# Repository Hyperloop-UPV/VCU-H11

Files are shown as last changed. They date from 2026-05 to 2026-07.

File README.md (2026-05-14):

# VCU-H11

Vehicle Control Unit firmware for Hyperloop UPV.

The VCU is the pod-level controller for the H11 custom board based on the STM32H723ZGT6. It coordinates the vehicle-facing control and telemetry functions around cooling, pressure regulation, braking support signals, SDC state, flow and temperature sensing, CAN, Ethernet, SD storage, and board status indication.

## Responsibilities

The firmware is responsible for:

- Initializing the VCU hardware through ST-LIB.
- Managing VCU operational modes.
- Reading pressure, temperature, flow, SDC, brake, and SD-card related inputs.
- Driving status LEDs and VCU actuators such as the two cooling pump outputs, electrovalve, PWM pressure regulator command path, brake reset, and CAN silent control.
- Publishing VCU telemetry and receiving commands through the generated packet interface.
- Evaluating protections and reporting diagnostics through ST-LIB infrastructure.

## Architecture

VCU-H11 is a C++23 STM32 firmware project built around ST-LIB.

Application code is organized around these entry points:

- `Core/Src/main.cpp`: firmware entry point.
- `Core/Inc/VCU.hpp`: VCU facade and `ST_LIB::Board<...>` definition.
- `Core/Inc/VCU_TYPES.hpp`: Board device declarations, runtime instances, sensors, and VCU state.
- `Core/Inc/Pinout/Pinout.hpp`: board pin aliases with firmware-facing names.
- `Core/Inc/StateMachine/VCU_StateMachine.hpp`: operational state machine.
- `Core/Inc/Code_generation/JSON_ADE/boards/VCU/`: packet schema inputs for generated communication code.

All hardware access should go through ST-LIB. Application code should use the highest-level ST-LIB abstraction that fits the hardware role, for example `LinearSensor` for linear analog sensors, `NTC` for NTC channels, `SensorInterrupt`/`EXTIDomain` for edge-triggered sensors, and Board-managed domain instances for lower-level peripherals.

Fault state ownership belongs to ST-LIB infrastructure. The VCU application state machine should describe operational modes, while protections and diagnostics handle fault behavior.

## Hardware References

Hardware design references are stored under `docs/`:

- `VCU.ioc`: STM32CubeMX pin and peripheral role reference.
- `VCU_H11G.zip`: Altium project archive.
- `Schematic PDF_[No Variations].pdf`: schematic PDF export.
- `Gerber for PCB.PcbDoc.zip`: PCB fabrication output.
- `STEP_[No Variations] for PCB.PcbDoc.step`: mechanical model.
- `Assembly Drawings_[No Variations].pdf`: assembly drawing export.
- `BOM_[No Variations].csv`: bill of materials export.

## Build And Flash

Use the local `hyper` helper CLI for common workflows:

```sh
./hyper doctor
./hyper build main --preset board-debug --board-name VCU
./hyper build main --preset board-debug-eth-lan8700 --board-name VCU
./hyper run main --preset board-debug --board-name VCU --uart
```

Useful environment variables:

- `HYPER_DEFAULT_PRESET`
- `HYPER_FLASH_METHOD`
- `HYPER_UART_PORT`
- `HYPER_UART_BAUD`
- `HYPER_UART_TOOL`

For UART sessions, `tio` is the recommended terminal tool.

## Packet Generation

The packet interface is generated from the ADJ schema for `BOARD_NAME=VCU`:

```text
Core/Inc/Code_generation/JSON_ADE/boards/VCU/
```

CMake regenerates packet headers during configure. Manual regeneration is also available:

```sh
python3 Core/Inc/Code_generation/Generator.py VCU
```

Generated packet headers are build outputs and should not be edited by hand:

- `Core/Inc/Communications/Packets/DataPackets.hpp`
- `Core/Inc/Communications/Packets/OrderPackets.hpp`

## Documentation

Project-specific AI and maintenance context:

- `AGENTS.md`
- `docs/ai/vcu-context.md`

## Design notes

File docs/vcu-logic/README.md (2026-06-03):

# VCU Logic Documentation

This folder documents the Vehicle Control Unit business logic extracted from the previous board codebase at `/Users/jsaegar/hyper-src/VCU-H10-V2`.

The H10-V2 project used an old ST-LIB API and several implementation details are no longer valid for H11. The durable part is the control intent: what the VCU supervises, which commands it accepts, how it gates them by state, what telemetry it reports, and what conditions push the vehicle into a safe fault response.

Use these documents as the behavioral reference when implementing H11 firmware. Do not copy the old H10 hardware-access style.

## Document Map

- [Purpose and Responsibilities](01-purpose-and-responsibilities.md): what the VCU is responsible for in the vehicle.
- [State Machine](02-state-machine.md): the general and operational states, transitions, and cyclic work.
- [Communications and Orders](03-communications-and-orders.md): sockets, packet flow, order handling, and remote-board acknowledgements.
- [Local Subsystems](04-local-subsystems.md): brakes, pressure regulation, pumps, sensors, and LEDs.
- [Protections and Faults](05-protections-and-faults.md): fault triggers, safety actions, and unresolved safety questions.
- [H11 Porting Notes](06-h11-porting-notes.md): how to carry the H10 behavior into the current H11 architecture.

## Mental Model

The VCU is the vehicle master. It is the coordinator between the operator/control station, local hardware attached to the VCU, and remote vehicle boards such as HVBMS, PCU, and LCU.

At a high level, each loop does four jobs:

1. Maintain infrastructure and communications.
2. Advance the vehicle state machines.
3. Read local sensors and publish telemetry.
4. Process accepted orders, forward remote requests, and fault if safety assumptions are violated.

The VCU does not directly implement every vehicle subsystem. Instead, it arbitrates when other boards may act. For example, it does not close the high-voltage contactors itself; it sends the contactor order to HVBMS, waits until HVBMS reports the expected state, then updates the VCU's own operational state.

## Source Caveats

The inspected H10-V2 snapshot contains legacy and partially disabled code paths:

- `state_machine.json` is a template example. The real VCU state machine is in `Core/Inc/state_machine.hpp`.
- BMSL, LCU, BCU, and some propulsion/charging paths are referenced, but some sockets or orders are commented out in the inspected snapshot.
- Some names are Spanish or legacy abbreviations. H11 firmware should keep English concept names.
- The H10 code modeled `Fault` as a general state. H11 should preserve the fault behavior through ST-LIB protections, diagnostics, and fault policy infrastructure rather than adding `Fault` to the application operational state.

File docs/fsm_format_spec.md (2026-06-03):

# Formato declarativo para definir máquinas de estados finitas

## 1. Objetivo

Este documento define un formato declarativo, legible por humanos y procesable por herramientas, para describir máquinas de estados finitas, o FSMs, de forma suficientemente precisa como para:

- Generar código automáticamente.
- Generar diagramas de estados.
- Generar tests unitarios.
- Revisar el comportamiento del sistema sin leer código imperativo.
- Pasar la especificación a una IA o agente de generación de código sin depender de texto ambiguo.

El formato recomendado es YAML, aunque puede traducirse directamente a JSON.

La idea principal es separar:

- La estructura de la máquina.
- La lógica de transición.
- Las condiciones de transición.
- Las acciones ejecutadas.
- La implementación concreta del hardware o del sistema real.

Una máquina de estados bien definida no debería depender de frases como “cuando pase algo, cambia a tal modo”. Debería declarar explícitamente qué evento provoca qué transición, bajo qué condición y qué acciones se ejecutan.

---

## 2. Modelo formal

Una máquina de estados se puede definir como:

```text
FSM = (S, E, G, A, T, s0, C)
```

Donde:

| Símbolo | Significado |
|---|---|
| `S` | Conjunto de estados |
| `E` | Conjunto de eventos |
| `G` | Conjunto de guards o condiciones booleanas |
| `A` | Conjunto de acciones |
| `T` | Conjunto de transiciones |
| `s0` | Estado inicial |
| `C` | Contexto o datos internos usados por la FSM |

Una transición se puede expresar como:

```text
estado_origen + evento + guard -> estado_destino + acciones
```

Ejemplo:

```text
IDLE + START [battery_connected && no_fault] -> PRECHARGE / enable_precharge(), reset_timer()
```

En YAML:

```yaml
- from: IDLE
  event: START
  guard: battery_connected && no_fault
  to: PRECHARGE
  actions:
    - enable_precharge
    - reset_timer
```

---

## 3. Estructura general del documento

Una especificación completa puede tener esta forma:

```yaml
schema_version: "1.0"
machine: ChargerFSM
description: Máquina de estados para control de carga de batería.

initial_state: IDLE

context:
  variables: []

states: []

events: []

guards: []

actions: []

transitions: []
```

Los campos principales son:

| Campo | Obligatorio | Descripción |
|---|---:|---|
| `schema_version` | Sí | Versión del formato usado |
| `machine` | Sí | Nombre de la máquina de estados |
| `description` | No | Descripción general |
| `initial_state` | Sí | Estado inicial |
| `context` | No | Variables internas usadas por guards y acciones |
| `states` | Sí | Lista o mapa de estados |
| `events` | Sí | Lista de eventos que la máquina acepta |
| `guards` | No | Lista de condiciones booleanas |
| `actions` | No | Lista de acciones ejecutables |
| `transitions` | Sí | Lista de transiciones |

---

## 4. `schema_version`

Indica la versión del formato de especificación.

```yaml
schema_version: "1.0"
```

Esto permite evolucionar el formato en el futuro sin romper generadores de código antiguos.

---

## 5. `machine`

Nombre lógico de la máquina de estados.

```yaml
machine: ChargerFSM
```

Recomendaciones:

- Usar `PascalCase`.
- Evitar espacios.
- Usar un nombre que pueda convertirse fácilmente en prefijo de funciones o tipos.

Por ejemplo, para C:

```c
typedef enum ChargerFSM_State { ... } ChargerFSM_State;
void ChargerFSM_dispatch(...);
```

---

## 6. `description`

Descripción humana del propósito de la máquina.

```yaml
description: >
  Controla el proceso de carga de una batería de alto voltaje,
  incluyendo precarga, carga activa, finalización y fallos.
```

Este campo no debería contener lógica normativa. La lógica debe estar en `transitions`, `guards` y `actions`.

---

## 7. `initial_state`

Estado inicial de la máquina.

```yaml
initial_state: IDLE
```

Debe coincidir exactamente con uno de los estados definidos en `states`.

---

## 8. `context`

El contexto define los datos que la FSM puede consultar o modificar.

Ejemplo:

```yaml
context:
  variables:
    - name: battery_voltage
      type: float
      unit: V
      access: read
      description: Tensión medida en la batería.

    - name: charge_current
      type: float
      unit: A
      access: read
      description: Corriente de carga medida.

    - name: fault_flags
      type: uint32_t
      access: read_write
      description: Máscara de bits con fallos activos.
```

Campos recomendados por variable:

| Campo | Obligatorio | Descripción |
|---|---:|---|
| `name` | Sí | Nombre de la variable |
| `type` | Sí | Tipo lógico o tipo de lenguaje destino |
| `unit` | No | Unidad física, si aplica |
| `access` | No | `read`, `write` o `read_write` |
| `description` | No | Descripción humana |
| `initial_value` | No | Valor inicial |
| `range` | No | Rango válido |

Ejemplo con rango:

```yaml
- name: battery_voltage
  type: float
  unit: V
  range:
    min: 0.0
    max: 500.0
```

---

## 9. `states`

Los estados representan situaciones discretas de la FSM.

Formato simple:

```yaml
states:
  - IDLE
  - PRECHARGE
  - CHARGING
  - DONE
  - FAULT
```

Formato recomendado:

```yaml
states:
  - name: IDLE
    description: Sistema parado esperando orden de arranque.
    on_entry:
      - disable_pwm
    on_exit: []

  - name: CHARGING
    description: Carga activa de la batería.
    on_entry:
      - enable_pwm
    on_exit:
      - disable_pwm
```

Campos posibles:

| Campo | Obligatorio | Descripción |
|---|---:|---|
| `name` | Sí | Nombre del estado |
| `description` | No | Descripción humana |
| `type` | No | Tipo especial: `normal`, `final`, `fault`, etc. |
| `on_entry` | No | Acciones al entrar al estado |
| `on_exit` | No | Acciones al salir del estado |
| `do` | No | Acciones periódicas mientras se permanece en el estado |
| `timeout` | No | Timeout asociado al estado |
| `internal_transitions` | No | Transiciones internas que no cambian de estado |
| `metadata` | No | Información extra para herramientas |

---

## 10. Acciones `on_entry`, `on_exit` y `do`

### `on_entry`

Acciones ejecutadas al entrar en un estado.

```yaml
on_entry:
  - enable_pwm
  - reset_state_timer
```

### `on_exit`

Acciones ejecutadas al salir de un estado.

```yaml
on_exit:
  - disable_pwm
```

### `do`

Acciones ejecutadas periódicamente mientras la FSM permanece en el estado.

```yaml
do:
  - update_control_loop
  - monitor_temperature
```

Recomendación: `do` debería usarse con cuidado. En sistemas embebidos suele corresponder a una función llamada periódicamente desde un tick o scheduler.

---

## 11. `timeout` de estado

Un estado puede tener un timeout.

```yaml
timeout:
  duration_ms: 5000
  event: TIMEOUT
  description: Si la precarga tarda más de 5 s, se genera TIMEOUT.
```

Campos posibles:

| Campo | Obligatorio | Descripción |
|---|---:|---|
| `duration_ms` | Sí | Duración en milisegundos |
| `event` | Sí | Evento generado al cumplirse el timeout |
| `description` | No | Descripción humana |

El generador puede implementar esto como:

- Temporizador interno de estado.
- Evento sintético generado por el scheduler.
- Comparación de timestamps.

---

## 12. `events`

Los eventos son entradas discretas que la FSM procesa.

Formato simple:

```yaml
events:
  - START
  - STOP
  - ADC_UPDATE
  - TIMEOUT
  - RESET
```

Formato recomendado:

```yaml
events:
  - name: START
    source: user_command
    description: Solicitud externa para iniciar la carga.

  - name: ADC_UPDATE
    source: periodic_task
    payload:
      - name: battery_voltage
        type: float
      - name: charge_current
        type: float
    description: Nueva muestra de ADC disponible.
```

Campos posibles:

| Campo | Obligatorio | Descripción |
|---|---:|---|
| `name` | Sí | Nombre del evento |
| `source` | No | Origen lógico del evento |
| `description` | No | Descripción humana |
| `payload` | No | Datos asociados al evento |
| `priority` | No | Prioridad del evento |

---

## 13. `guards`

Los guards son condiciones booleanas que habilitan o bloquean transiciones.

```yaml
guards:
  - name: battery_connected
    expression: battery_voltage > 50.0
    description: La batería está conectada si su tensión supera 50 V.
```

Campos posibles:

| Campo | Obligatorio | Descripción |
|---|---:|---|
| `name` | Sí | Nombre del guard |
| `expression` | No | Expresión lógica abstracta |
| `function` | No | Nombre de función que lo implementa |
| `description` | No | Descripción humana |
| `dependencies` | No | Variables de contexto usadas |

Hay dos estilos válidos.

### 13.1 Guard como expresión

```yaml
- name: current_too_high
  expression: charge_current > max_charge_current
```

El generador puede convertir esto a código si el lenguaje y las variables están bien definidas.

### 13.2 Guard como función externa

```yaml
- name: current_too_high
  function: guard_current_too_high
```

El generador solo declara la función, pero no la implementa.

Ejemplo en C:

```c
bool guard_current_too_high(const ChargerFSM_Context *ctx);
```

---

## 14. `actions`

Las acciones son operaciones ejecutadas por la FSM.

```yaml
actions:
  - name: enable_pwm
    function: action_enable_pwm
    description: Habilita la etapa de potencia.
```

Campos posibles:

| Campo | Obligatorio | Descripción |
|---|---:|---|
| `name` | Sí | Nombre lógico de la acción |
| `function` | No | Nombre de función destino |
| `description` | No | Descripción humana |
| `parameters` | No | Parámetros |
| `modifies` | No | Variables de contexto modificadas |
| `blocking` | No | Indica si la acción bloquea |

Ejemplo con parámetros:

```yaml
- name: set_fault_reason
  function: action_set_fault_reason
  parameters:
    - name: reason
      type: FaultReason
```

Uso en una transición:

```yaml
actions:
  - name: set_fault_reason
    args:
      reason: OVERCURRENT
```

---

## 15. `transitions`

Las transiciones definen el comportamiento principal.

```yaml
transitions:
  - from: IDLE
    event: START
    guard: battery_connected && no_fault
    to: PRECHARGE
    actions:
      - reset_timer
      - enable_precharge
```

Campos posibles:

| Campo | Obligatorio | Descripción |
|---|---:|---|
| `from` | Sí | Estado origen |
| `event` | Sí | Evento que dispara la transición |
| `guard` | No | Condición necesaria |
| `to` | Sí | Estado destino |
| `actions` | No | Acciones asociadas a la transición |
| `priority` | No | Prioridad explícita |
| `description` | No | Descripción humana |

---

## 16. Orden y prioridad de transiciones

Si varias transiciones tienen el mismo `from` y el mismo `event`, puede haber ambigüedad.

Ejemplo:

```yaml
- from: CHARGING
  event: ADC_UPDATE
  guard: current_too_high
  to: FAULT

- from: CHARGING
  event: ADC_UPDATE
  guard: voltage_reached
  to: DONE
```

Si ambas condiciones pueden ser verdaderas a la vez, el resultado depende del orden o de una prioridad explícita.

Forma recomendada:

```yaml
- from: CHARGING
  event: ADC_UPDATE
  guard: current_too_high
  to: FAULT
  priority: 10

- from: CHARGING
  event: ADC_UPDATE
  guard: voltage_reached
  to: DONE
  priority: 20
```

Regla recomendada:

- Menor valor de `priority` implica mayor prioridad.
- Si no hay `priority`, se respeta el orden de aparición.
- Un validador debería avisar si hay condiciones potencialmente solapadas.

---

## 17. Transiciones globales

Una transición global aplica desde cualquier estado.

```yaml
- from: "*"
  event: EMERGENCY_STOP
  to: FAULT
  actions:
    - disable_pwm
    - open_contactor
    - set_fault_emergency_stop
  priority: 0
```

Uso típico:

- Parada de emergencia.
- Fallo crítico.
- Reset global.
- Pérdida de comunicación.

---

## 18. Transiciones internas

Una transición interna procesa un evento sin cambiar de estado.

```yaml
- from: CHARGING
  event: ADC_UPDATE
  guard: normal_operating_conditions
  to: CHARGING
  internal: true
  actions:
    - update_control_loop
```

También puede representarse dentro del estado:

```yaml
states:
  - name: CHARGING
    internal_transitions:
      - event: ADC_UPDATE
        guard: normal_operating_conditions
        actions:
          - update_control_loop
```

Recomendación:

- Usar `internal: true` si quieres que no se ejecuten `on_exit` ni `on_entry`.
- Usar `to: CHARGING` sin `internal: true` si quieres que sí se ejecuten salida y entrada del mismo estado.

---

## 19. Transiciones sin guard

Una transición sin guard se considera siempre habilitada.

```yaml
- from: IDLE
  event: START
  to: RUNNING
```

Equivale a:

```yaml
guard: true
```

---

## 20. Acciones parametrizadas en transiciones

Las acciones pueden llamarse directamente por nombre:

```yaml
actions:
  - disable_pwm
```

O con argumentos:

```yaml
actions:
  - name: set_fault_reason
    args:
      reason: OVERTEMPERATURE
  - name: log_event
    args:
      event_id: CHARGER_FAULT
```

Esto permite generar llamadas como:

```c
action_set_fault_reason(ctx, FAULT_OVERTEMPERATURE);
action_log_event(ctx, CHARGER_FAULT);
```

---

## 21. Estados finales

Un estado final representa una condición terminal.

```yaml
- name: DONE
  type: final
  description: Proceso completado correctamente.
```

Un generador puede usar esto para:

- No esperar más eventos.
- Generar una función `is_finished()`.
- Marcar el estado como terminal en un diagrama.

---

## 22. Estados de fallo

Un estado de fallo representa una condición anómala.

```yaml
- name: FAULT
  type: fault
  on_entry:
    - disable_pwm
    - open_contactor
    - log_fault
```

No todos los fallos tienen que ir al mismo estado, pero suele ser útil tener un estado `FAULT` común y guardar la causa del fallo en el contexto.

---

## 23. Historial de estado

Algunas máquinas jerárquicas necesitan recordar el último subestado activo.

Ejemplo:

```yaml
history:
  enabled: true
  type: shallow
```

Tipos posibles:

| Tipo | Significado |
|---|---|
| `shallow` | Recuerda solo el subestado directo |
| `deep` | Recuerda toda la jerarquía de subestados |

Este campo es opcional y solo tiene sentido en máquinas jerárquicas.

---

## 24. Estados jerárquicos

Para máquinas complejas se pueden usar estados con subestados.

```yaml
states:
  - name: ACTIVE
    initial_state: PRECHARGE
    substates:
      - name: PRECHARGE
      - name: CHARGING
      - name: BALANCING
```

Esto representa una máquina jerárquica tipo statechart.

Recomendación:

- Usar FSM plana para sistemas pequeños.
- Usar jerarquía cuando haya estados que compartan transiciones, acciones o comportamiento común.

---

## 25. Eventos diferidos

Un estado puede diferir eventos para procesarlos más tarde.

```yaml
states:
  - name: PRECHARGE
    defer:
      - START_BALANCING
```

Esto significa que, si llega `START_BALANCING` durante `PRECHARGE`, no se descarta, sino que se guarda hasta que la FSM entre en un estado donde pueda procesarlo.

---

## 26. Eventos ignorados explícitamente

Puedes declarar eventos ignorados para dejar claro que no es un olvido.

```yaml
states:
  - name: IDLE
    ignore:
      - ADC_UPDATE
      - TIMEOUT
```

Esto ayuda a diferenciar entre:

- Evento no contemplado por error.
- Evento ignorado intencionadamente.

---

## 27. Política para eventos no manejados

Puede definirse a nivel global.

```yaml
unhandled_event_policy:
  behavior: ignore
  action: log_unhandled_event
```

Opciones típicas:

| Valor | Significado |
|---|---|
| `ignore` | Ignorar el evento |
| `log` | Registrar el evento |
| `fault` | Ir a estado de fallo |
| `assert` | Disparar una aserción en debug |

---

## 28. Invariantes de estado

Un invariante es una condición que debe cumplirse mientras la FSM esté en un estado.

```yaml
states:
  - name: CHARGING
    invariants:
      - pwm_enabled == true
      - contactor_closed == true
```

Si un invariante falla, el sistema puede:

- Registrar error.
- Ir a `FAULT`.
- Activar una aserción en debug.

---

## 29. Validaciones recomendadas

Un validador de especificación debería comprobar:

1. `initial_state` existe en `states`.
2. Todos los `from` existen, salvo `"*"`.
3. Todos los `to` existen.
4. Todos los `event` existen.
5. Todos los guards usados existen o son expresiones válidas.
6. Todas las acciones usadas existen.
7. No hay estados inalcanzables, salvo que estén marcados como intencionados.
8. No hay transiciones ambiguas sin prioridad.
9. No hay estados sin salida salvo estados `final` o `fault`.
10. No hay eventos definidos pero nunca usados, salvo que estén marcados como reservados.

---

## 30. Generación de código

Un generador puede producir:

- Enumeraciones de estados.
- Enumeraciones de eventos.
- Estructura de contexto.
- Función `init`.
- Función `dispatch`.
- Función `tick` para timeouts y acciones `do`.
- Prototipos de guards.
- Prototipos de acciones.
- Tabla de transiciones.
- Tests unitarios.

Ejemplo de API generada en C:

```c
typedef enum {
    CHARGER_STATE_IDLE,
    CHARGER_STATE_PRECHARGE,
    CHARGER_STATE_CHARGING,
    CHARGER_STATE_DONE,
    CHARGER_STATE_FAULT
} ChargerFSM_State;

typedef enum {
    CHARGER_EVENT_START,
    CHARGER_EVENT_STOP,
    CHARGER_EVENT_ADC_UPDATE,
    CHARGER_EVENT_TIMEOUT,
    CHARGER_EVENT_RESET
} ChargerFSM_Event;

void ChargerFSM_init(ChargerFSM_Context *ctx);
void ChargerFSM_dispatch(ChargerFSM_Context *ctx, ChargerFSM_Event event);
void ChargerFSM_tick(ChargerFSM_Context *ctx, uint32_t elapsed_ms);
ChargerFSM_State ChargerFSM_get_state(const ChargerFSM_Context *ctx);
```

---

## 31. Reglas recomendadas para IA o agentes de código

Cuando se pase esta especificación a una IA, conviene añadir instrucciones como:

```text
Generate production-quality C code from this FSM specification.

Rules:
- Do not invent states, events, guards or actions.
- Preserve transition priority.
- Use the order listed when priority is not specified.
- Generate external prototypes for guards and actions.
- Do not implement hardware-specific functions unless explicitly defined.
- Generate unit-testable code.
- If the FSM specification is ambiguous, mark the affected part as TODO instead of inventing behavior.
```

---

## 32. Plantilla mínima

```yaml
schema_version: "1.0"
machine: ExampleFSM
initial_state: IDLE

states:
  - name: IDLE
  - name: RUNNING
  - name: FAULT
    type: fault

events:
  - name: START
  - name: STOP
  - name: ERROR
  - name: RESET

guards:
  - name: no_fault
    expression: fault_flags == 0

actions:
  - name: start_system
  - name: stop_system
  - name: clear_faults

transitions:
  - from: IDLE
    event: START
    guard: no_fault
    to: RUNNING
    actions:
      - start_system

  - from: RUNNING
    event: STOP
    to: IDLE
    actions:
      - stop_system

  - from: "*"
    event: ERROR
    to: FAULT
    actions:
      - stop_system

  - from: FAULT
    event: RESET
    to: IDLE
    actions:
      - clear_faults
```

---

## 33. Plantilla completa recomendada

```yaml
schema_version: "1.0"
machine: NameFSM
description: Descripción general de la máquina.

initial_state: IDLE

unhandled_event_policy:
  behavior: log
  action: log_unhandled_event

context:
  variables:
    - name: variable_name
      type: uint32_t
      access: read_write
      description: Descripción.

states:
  - name: IDLE
    type: normal
    description: Estado inicial.
    on_entry: []
    on_exit: []
    do: []
    ignore: []
    defer: []
    invariants: []

  - name: FAULT
    type: fault
    on_entry:
      - safe_shutdown

events:
  - name: START
    source: external
    description: Evento de arranque.

guards:
  - name: can_start
    expression: fault_flags == 0
    dependencies:
      - fault_flags

actions:
  - name: safe_shutdown
    function: action_safe_shutdown
    description: Lleva el sistema a estado seguro.

transitions:
  - from: IDLE
    event: START
    guard: can_start
    to: RUNNING
    actions:
      - initialize_system
    priority: 10
    description: Arranca el sistema si no hay fallos.
```

---

## 34. Recomendaciones de estilo

- Nombres de estados en `UPPER_SNAKE_CASE`.
- Nombres de eventos en `UPPER_SNAKE_CASE`.
- Nombres de guards en `lower_snake_case`.
- Nombres de acciones en `lower_snake_case`.
- Evitar lógica compleja dentro de `transitions`.
- Dar prioridad explícita a transiciones críticas de seguridad.
- Separar la FSM del hardware.
- No esconder comportamiento en descripciones en lenguaje natural.

---

## 35. Regla práctica

Una buena especificación de FSM debería poder responder claramente a estas preguntas:

1. ¿En qué estado empieza?
2. ¿Qué eventos acepta?
3. ¿Qué puede pasar desde cada estado?
4. ¿Qué condiciones bloquean o permiten cada transición?
5. ¿Qué acciones se ejecutan al entrar, salir o cambiar de estado?
6. ¿Qué pasa ante eventos no esperados?
7. ¿Qué pasa ante errores o timeouts?
8. ¿Hay transiciones críticas con prioridad clara?

Si alguna de estas preguntas no se puede responder leyendo el YAML, la máquina todavía no está suficientemente formalizada.

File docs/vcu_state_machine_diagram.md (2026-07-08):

# VCU State Machine Diagram

This diagram follows `docs/vcu_state_machine.yaml`.

```mermaid
stateDiagram-v2
    direction LR

    [*] --> IDLE

    IDLE: IDLE\nbrake, open contactors\nwait for required links
    CONNECTED: CONNECTED\nbrake, open contactors\nwait for MANTEINANCE or PRECHARGE
    MANTEINANCE: MANTEINANCE\nunbrake\nwait for STOP
    PRECHARGING: PRECHARGING\nsend precharge\nwait for STOP or HVBMS completion
    HV_ACTIVE: HV_ACTIVE\nwait for STOP or UNBRAKE
    READY: READY\nunbrake\nwait for BRAKE/STOP/PROPULSION/LEVITATION
    PROPULSION: PROPULSION\nforward propulsion orders
    STATIC_LEVITATION: STATIC_LEVITATION\nforward static levitation orders
    DYNAMIC_LEVITATION: DYNAMIC_LEVITATION\nforward dynamic levitation orders
    FAULT: FAULT\nopen SDC, fault LED,\npropagate fault, open contactors

    IDLE --> CONNECTED: CONNECTIONS_READY\ncontrol station + required boards connected

    CONNECTED --> MANTEINANCE: ORDER_MANTEINANCE
    CONNECTED --> PRECHARGING: ORDER_PRECHARGE

    MANTEINANCE --> CONNECTED: ORDER_STOP

    PRECHARGING --> CONNECTED: ORDER_STOP
    PRECHARGING --> HV_ACTIVE: PRECHARGE_COMPLETE\nfrom HVBMS

    HV_ACTIVE --> CONNECTED: ORDER_STOP
    HV_ACTIVE --> READY: ORDER_UNBRAKE

    READY --> CONNECTED: ORDER_STOP
    READY --> HV_ACTIVE: ORDER_BRAKE
    READY --> PROPULSION: ORDER_PROPULSION
    READY --> STATIC_LEVITATION: ORDER_STATIC_LEVITATION
    READY --> DYNAMIC_LEVITATION: ORDER_DYNAMIC_LEVITATION

    STATIC_LEVITATION --> DYNAMIC_LEVITATION: ORDER_DYNAMIC_LEVITATION

    PROPULSION --> HV_ACTIVE: ORDER_BRAKE\nbrake, keep contactors closed
    STATIC_LEVITATION --> HV_ACTIVE: ORDER_BRAKE\nbrake, keep contactors closed
    DYNAMIC_LEVITATION --> HV_ACTIVE: ORDER_BRAKE\nbrake, keep contactors closed

    PROPULSION --> CONNECTED: ORDER_STOP\nstop propelling
    STATIC_LEVITATION --> CONNECTED: ORDER_STOP\nstop levitating
    DYNAMIC_LEVITATION --> CONNECTED: ORDER_STOP\nstop propelling + levitating

    PROPULSION --> PROPULSION: propulsion-specific orders
    STATIC_LEVITATION --> STATIC_LEVITATION: static-levitation-specific orders
    DYNAMIC_LEVITATION --> DYNAMIC_LEVITATION: propulsion + levitation orders

    IDLE --> IDLE: high pressure < 50 bar\nemit warning
    CONNECTED --> CONNECTED: high pressure < 50 bar\nemit warning
    HV_ACTIVE --> HV_ACTIVE: high pressure < 50 bar\nemit warning
    READY --> READY: high pressure < 50 bar\nemit warning

    IDLE --> FAULT: SDC open / brake fault /\ntapes reached / control station disconnected
    CONNECTED --> FAULT: SDC open / brake fault /\ntapes reached / control station disconnected
    MANTEINANCE --> FAULT: SDC open / brake fault /\ntapes reached / control station disconnected
    PRECHARGING --> FAULT: SDC open / brake fault /\ntapes reached / control station disconnected
    HV_ACTIVE --> FAULT: SDC open / brake fault /\ntapes reached / control station disconnected
    READY --> FAULT: SDC open / brake fault /\ntapes reached / control station disconnected
    PROPULSION --> FAULT: SDC open / brake fault /\ntapes reached / control station disconnected
    STATIC_LEVITATION --> FAULT: SDC open / brake fault /\ntapes reached / control station disconnected
    DYNAMIC_LEVITATION --> FAULT: SDC open / brake fault /\ntapes reached / control station disconnected
```

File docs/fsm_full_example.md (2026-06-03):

# Ejemplo completo de máquina de estados declarativa

Este documento contiene una máquina de estados de ejemplo que usa prácticamente todos los elementos definibles del formato propuesto.

El ejemplo representa un cargador de batería de alto voltaje con:

- Estado inicial.
- Estados normales.
- Estado final.
- Estado de fallo.
- Estados jerárquicos.
- Acciones `on_entry`, `on_exit` y `do`.
- Timeouts.
- Eventos con payload.
- Guards por expresión y por función.
- Acciones simples y parametrizadas.
- Transiciones normales.
- Transiciones globales.
- Transiciones internas.
- Eventos ignorados.
- Eventos diferidos.
- Invariantes.
- Política de eventos no manejados.
- Prioridad explícita.
- Metadata para generación de código.

---

## Máquina de estados de ejemplo

```yaml
schema_version: "1.0"

machine: HighVoltageChargerFSM

description: >
  Máquina de estados para controlar un cargador de batería de alto voltaje.
  Incluye inicialización, autodiagnóstico, espera, precarga, carga activa,
  balanceo, finalización, parada ordenada y gestión de fallos.

metadata:
  author: Example
  target_language: c
  intended_platform: embedded
  tick_period_ms: 1
  codegen:
    generate_switch_dispatcher: true
    generate_transition_table: true
    generate_unit_tests: true
    generate_dot_diagram: true
    externalize_guards: true
    externalize_actions: true
    state_enum_prefix: HVCHG_STATE_
    event_enum_prefix: HVCHG_EVENT_
    function_prefix: HVChargerFSM_

initial_state: BOOT

unhandled_event_policy:
  behavior: log
  action: log_unhandled_event
  description: >
    Los eventos no manejados se registran, pero no cambian el estado de la FSM.

context:
  description: Datos internos consultados o modificados por la FSM.
  variables:
    - name: battery_voltage
      type: float
      unit: V
      access: read
      initial_value: 0.0
      range:
        min: 0.0
        max: 500.0
      description: Tensión medida en la batería.

    - name: dc_bus_voltage
      type: float
      unit: V
      access: read
      initial_value: 0.0
      range:
        min: 0.0
        max: 500.0
      description: Tensión del bus DC del cargador.

    - name: charge_current
      type: float
      unit: A
      access: read
      initial_value: 0.0
      range:
        min: -10.0
        max: 100.0
      description: Corriente medida de carga.

    - name: temperature_heatsink
      type: float
      unit: degC
      access: read
      initial_value: 25.0
      range:
        min: -40.0
        max: 150.0
      description: Temperatura del disipador.

    - name: target_voltage
      type: float
      unit: V
      access: read_write
      initial_value: 400.0
      description: Tensión objetivo de carga.

    - name: max_charge_current
      type: float
      unit: A
      access: read_write
      initial_value: 20.0
      description: Corriente máxima permitida.

    - name: fault_flags
      type: uint32_t
      access: read_write
      initial_value: 0
      description: Máscara de bits con fallos activos.

    - name: fault_reason
      type: FaultReason
      access: read_write
      initial_value: NONE
      description: Última causa de fallo registrada.

    - name: state_elapsed_ms
      type: uint32_t
      unit: ms
      access: read_write
      initial_value: 0
      description: Tiempo transcurrido desde la entrada al estado actual.

    - name: retry_counter
      type: uint8_t
      access: read_write
      initial_value: 0
      range:
        min: 0
        max: 3
      description: Contador de reintentos de arranque.

constants:
  - name: PRECHARGE_MIN_VOLTAGE
    type: float
    value: 50.0
    unit: V

  - name: PRECHARGE_TARGET_RATIO
    type: float
    value: 0.95

  - name: MAX_HEATSINK_TEMP
    type: float
    value: 85.0
    unit: degC

  - name: MAX_RETRIES
    type: uint8_t
    value: 3

states:
  - name: BOOT
    type: normal
    description: Estado inicial tras reset del microcontrolador.
    on_entry:
      - initialize_context
      - disable_pwm
      - open_main_contactor
      - open_precharge_contactor
    on_exit:
      - reset_state_timer
    timeout:
      duration_ms: 1000
      event: TIMEOUT
      description: El arranque no debería tardar más de 1 s.
    ignore:
      - ADC_UPDATE
      - STOP
    invariants:
      - pwm_enabled == false
      - main_contactor_closed == false

  - name: SELF_TEST
    type: normal
    description: Ejecuta comprobaciones internas antes de permitir carga.
    on_entry:
      - start_self_test
      - reset_state_timer
    do:
      - poll_self_test
    on_exit:
      - stop_self_test
    timeout:
      duration_ms: 3000
      event: TIMEOUT
      description: Si el autodiagnóstico tarda más de 3 s, se genera fallo.
    defer:
      - START
    invariants:
      - pwm_enabled == false

  - name: IDLE
    type: normal
    description: Sistema seguro esperando orden de arranque.
    on_entry:
      - disable_pwm
      - open_main_contactor
      - open_precharge_contactor
      - clear_runtime_measurements
    ignore:
      - ADC_UPDATE
      - TIMEOUT
    invariants:
      - pwm_enabled == false

  - name: ACTIVE
    type: composite
    description: Estado jerárquico que agrupa las fases activas de carga.
    initial_state: PRECHARGE
    history:
      enabled: true
      type: shallow
    on_entry:
      - reset_state_timer
      - enable_measurements
    on_exit:
      - disable_pwm
      - open_precharge_contactor
      - open_main_contactor
    substates:
      - name: PRECHARGE
        type: normal
        description: Igualación gradual del bus DC antes de cerrar contactor principal.
        on_entry:
          - close_precharge_contactor
          - reset_state_timer
        on_exit:
          - open_precharge_contactor
        do:
          - update_measurements
          - monitor_precharge_progress
        timeout:
          duration_ms: 5000
          event: TIMEOUT
          description: La precarga debe completarse antes de 5 s.
        invariants:
          - pwm_enabled == false
          - precharge_contactor_closed == true

      - name: CLOSE_MAIN_CONTACTOR
        type: normal
        description: Cierra el contactor principal cuando la precarga es válida.
        on_entry:
          - close_main_contactor
          - reset_state_timer
        timeout:
          duration_ms: 500
          event: TIMEOUT
        invariants:
          - precharge_contactor_closed == true

      - name: CHARGING_CC
        type: normal
        description: Fase de carga en corriente constante.
        on_entry:
          - enable_pwm
          - configure_current_control
          - reset_state_timer
        do:
          - update_measurements
          - run_current_control_loop
          - monitor_temperature
        on_exit:
          - freeze_current_controller
        invariants:
          - pwm_enabled == true
          - main_contactor_closed == true

      - name: CHARGING_CV
        type: normal
        description: Fase de carga en tensión constante.
        on_entry:
          - configure_voltage_control
          - reset_state_timer
        do:
          - update_measurements
          - run_voltage_control_loop
          - monitor_temperature
        on_exit:
          - freeze_voltage_controller
        invariants:
          - pwm_enabled == true
          - main_contactor_closed == true

      - name: BALANCING
        type: normal
        description: Balanceo de celdas al final de la carga.
        on_entry:
          - enable_balancing
          - reset_state_timer
        do:
          - update_measurements
          - run_balancing_control
        on_exit:
          - disable_balancing
        timeout:
          duration_ms: 600000
          event: TIMEOUT
          description: El balanceo no debe exceder 10 minutos.
        defer:
          - START
        invariants:
          - main_contactor_closed == true

  - name: STOPPING
    type: normal
    description: Parada ordenada del sistema.
    on_entry:
      - disable_pwm
      - ramp_down_outputs
      - reset_state_timer
    do:
      - monitor_output_shutdown
    timeout:
      duration_ms: 2000
      event: TIMEOUT
    invariants:
      - pwm_enabled == false

  - name: DONE
    type: final
    description: Carga completada correctamente.
    on_entry:
      - disable_pwm
      - open_precharge_contactor
      - open_main_contactor
      - mark_charge_complete
    ignore:
      - ADC_UPDATE
      - TIMEOUT

  - name: FAULT
    type: fault
    description: Estado seguro tras detectar un fallo.
    on_entry:
      - disable_pwm
      - disable_balancing
      - open_precharge_contactor
      - open_main_contactor
      - log_fault
    do:
      - blink_fault_led
    ignore:
      - START
      - ADC_UPDATE
      - TIMEOUT
    invariants:
      - pwm_enabled == false
      - main_contactor_closed == false

  - name: LOCKED_OUT
    type: fault
    description: Estado de bloqueo tras demasiados reintentos fallidos.
    on_entry:
      - disable_pwm
      - open_precharge_contactor
      - open_main_contactor
      - log_lockout
    ignore:
      - START
      - ADC_UPDATE
      - RESET

events:
  - name: POWER_ON
    source: system
    description: Evento generado al inicializar la FSM.

  - name: SELF_TEST_OK
    source: self_test_task
    description: Autodiagnóstico completado correctamente.

  - name: SELF_TEST_FAILED
    source: self_test_task
    payload:
      - name: diagnostic_code
        type: uint32_t
    description: El autodiagnóstico ha fallado.

  - name: START
    source: user_command
    description: Solicitud de inicio de carga.

  - name: STOP
    source: user_command
    description: Solicitud de parada ordenada.

  - name: EMERGENCY_STOP
    source: safety_input
    priority: 0
    description: Parada de emergencia de máxima prioridad.

  - name: ADC_UPDATE
    source: periodic_task
    payload:
      - name: battery_voltage
        type: float
        unit: V
      - name: charge_current
        type: float
        unit: A
      - name: temperature_heatsink
        type: float
        unit: degC
    description: Nuevas medidas analógicas disponibles.

  - name: PRECHARGE_COMPLETE
    source: internal
    description: La precarga ha alcanzado el umbral requerido.

  - name: MAIN_CONTACTOR_CLOSED
    source: io_feedback
    description: Realimentación de contactor principal cerrado.

  - name: VOLTAGE_TARGET_REACHED
    source: control_loop
    description: Se ha alcanzado la tensión objetivo.

  - name: CURRENT_TAPERED
    source: control_loop
    description: La corriente ha bajado por debajo del umbral de fin de carga.

  - name: BALANCING_COMPLETE
    source: balancing_task
    description: Balanceo de celdas completado.

  - name: TIMEOUT
    source: generated_by_fsm
    description: Evento sintético generado por timeout de estado.

  - name: FAULT_DETECTED
    source: safety_monitor
    payload:
      - name: fault_reason
        type: FaultReason
    priority: 1
    description: Se ha detectado un fallo.

  - name: RESET
    source: user_command
    description: Solicitud de reset de fallo.

guards:
  - name: always
    expression: true
    description: Guard siempre verdadero.

  - name: no_fault
    expression: fault_flags == 0
    dependencies:
      - fault_flags
    description: No hay fallos activos.

  - name: battery_connected
    expression: battery_voltage > PRECHARGE_MIN_VOLTAGE
    dependencies:
      - battery_voltage
      - PRECHARGE_MIN_VOLTAGE
    description: La batería parece estar conectada.

  - name: precharge_voltage_reached
    expression: dc_bus_voltage >= battery_voltage * PRECHARGE_TARGET_RATIO
    dependencies:
      - dc_bus_voltage
      - battery_voltage
      - PRECHARGE_TARGET_RATIO
    description: El bus DC está suficientemente cerca de la tensión de batería.

  - name: main_contactor_feedback_ok
    function: guard_main_contactor_feedback_ok
    description: Comprueba por GPIO o feedback externo que el contactor principal está cerrado.

  - name: voltage_target_reached
    expression: battery_voltage >= target_voltage
    dependencies:
      - battery_voltage
      - target_voltage
    description: La batería ha alcanzado la tensión objetivo.

  - name: charge_current_below_finish_threshold
    function: guard_charge_current_below_finish_threshold
    description: La corriente ha bajado lo suficiente para finalizar la fase CV.

  - name: current_too_high
    expression: charge_current > max_charge_current
    dependencies:
      - charge_current
      - max_charge_current
    description: Sobrecorriente de carga.

  - name: temperature_too_high
    expression: temperature_heatsink > MAX_HEATSINK_TEMP
    dependencies:
      - temperature_heatsink
      - MAX_HEATSINK_TEMP
    description: Sobretemperatura del disipador.

  - name: can_retry
    expression: retry_counter < MAX_RETRIES
    dependencies:
      - retry_counter
      - MAX_RETRIES
    description: Todavía quedan reintentos permitidos.

  - name: cannot_retry
    expression: retry_counter >= MAX_RETRIES
    dependencies:
      - retry_counter
      - MAX_RETRIES
    description: Se han agotado los reintentos.

  - name: fault_cleared
    function: guard_fault_cleared
    description: El fallo ha desaparecido y el sistema puede volver a IDLE.

actions:
  - name: initialize_context
    function: action_initialize_context
    modifies:
      - fault_flags
      - fault_reason
      - retry_counter
      - state_elapsed_ms
    blocking: false
    description: Inicializa variables internas de la FSM.

  - name: reset_state_timer
    function: action_reset_state_timer
    modifies:
      - state_elapsed_ms
    blocking: false

  - name: disable_pwm
    function: action_disable_pwm
    blocking: false
    description: Deshabilita las señales PWM de la etapa de potencia.

  - name: enable_pwm
    function: action_enable_pwm
    blocking: false
    description: Habilita las señales PWM.

  - name: open_main_contactor
    function: action_open_main_contactor
    blocking: false

  - name: close_main_contactor
    function: action_close_main_contactor
    blocking: false

  - name: open_precharge_contactor
    function: action_open_precharge_contactor
    blocking: false

  - name: close_precharge_contactor
    function: action_close_precharge_contactor
    blocking: false

  - name: start_self_test
    function: action_start_self_test
    blocking: false

  - name: poll_self_test
    function: action_poll_self_test
    blocking: false

  - name: stop_self_test
    function: action_stop_self_test
    blocking: false

  - name: enable_measurements
    function: action_enable_measurements
    blocking: false

  - name: update_measurements
    function: action_update_measurements
    blocking: false

  - name: monitor_precharge_progress
    function: action_monitor_precharge_progress
    blocking: false

  - name: configure_current_control
    function: action_configure_current_control
    blocking: false

  - name: configure_voltage_control
    function: action_configure_voltage_control
    blocking: false

  - name: run_current_control_loop
    function: action_run_current_control_loop
    blocking: false

  - name: run_voltage_control_loop
    function: action_run_voltage_control_loop
    blocking: false

  - name: freeze_current_controller
    function: action_freeze_current_controller
    blocking: false

  - name: freeze_voltage_controller
    function: action_freeze_voltage_controller
    blocking: false

  - name: monitor_temperature
    function: action_monitor_temperature
    blocking: false

  - name: enable_balancing
    function: action_enable_balancing
    blocking: false

  - name: run_balancing_control
    function: action_run_balancing_control
    blocking: false

  - name: disable_balancing
    function: action_disable_balancing
    blocking: false

  - name: ramp_down_outputs
    function: action_ramp_down_outputs
    blocking: false

  - name: monitor_output_shutdown
    function: action_monitor_output_shutdown
    blocking: false

  - name: mark_charge_complete
    function: action_mark_charge_complete
    blocking: false

  - name: clear_runtime_measurements
    function: action_clear_runtime_measurements
    blocking: false

  - name: log_unhandled_event
    function: action_log_unhandled_event
    blocking: false

  - name: log_fault
    function: action_log_fault
    blocking: false

  - name: log_lockout
    function: action_log_lockout
    blocking: false

  - name: blink_fault_led
    function: action_blink_fault_led
    blocking: false

  - name: increment_retry_counter
    function: action_increment_retry_counter
    modifies:
      - retry_counter
    blocking: false

  - name: clear_faults
    function: action_clear_faults
    modifies:
      - fault_flags
      - fault_reason
    blocking: false

  - name: set_fault_reason
    function: action_set_fault_reason
    parameters:
      - name: reason
        type: FaultReason
    modifies:
      - fault_reason
    blocking: false

  - name: log_event
    function: action_log_event
    parameters:
      - name: event_id
        type: LogEventId
    blocking: false

transitions:
  # -------------------------------------------------------------------------
  # Arranque e inicialización
  # -------------------------------------------------------------------------

  - from: BOOT
    event: POWER_ON
    to: SELF_TEST
    actions:
      - reset_state_timer
    priority: 10
    description: Tras inicialización básica, se entra en autodiagnóstico.

  - from: BOOT
    event: TIMEOUT
    to: FAULT
    actions:
      - name: set_fault_reason
        args:
          reason: BOOT_TIMEOUT
      - log_fault
    priority: 5
    description: Fallo si BOOT no progresa a tiempo.

  - from: SELF_TEST
    event: SELF_TEST_OK
    to: IDLE
    actions:
      - clear_faults
    priority: 10

  - from: SELF_TEST
    event: SELF_TEST_FAILED
    to: FAULT
    actions:
      - name: set_fault_reason
        args:
          reason: SELF_TEST_FAILED
      - log_fault
    priority: 5

  - from: SELF_TEST
    event: TIMEOUT
    to: FAULT
    actions:
      - name: set_fault_reason
        args:
          reason: SELF_TEST_TIMEOUT
      - log_fault
    priority: 5

  # -------------------------------------------------------------------------
  # Entrada en carga
  # -------------------------------------------------------------------------

  - from: IDLE
    event: START
    guard: battery_connected && no_fault
    to: ACTIVE.PRECHARGE
    actions:
      - reset_state_timer
      - name: log_event
        args:
          event_id: CHARGE_STARTED
    priority: 20
    description: Inicia la secuencia de carga si la batería está conectada y no hay fallos.

  - from: IDLE
    event: START
    guard: battery_connected == false
    to: FAULT
    actions:
      - name: set_fault_reason
        args:
          reason: BATTERY_NOT_CONNECTED
      - log_fault
    priority: 10
    description: Rechaza el arranque si no se detecta batería.

  # -------------------------------------------------------------------------
  # Secuencia activa: precarga y contactor principal
  # -------------------------------------------------------------------------

  - from: ACTIVE.PRECHARGE
    event: ADC_UPDATE
    guard: current_too_high
    to: FAULT
    actions:
      - name: set_fault_reason
        args:
          reason: PRECHARGE_OVERCURRENT
      - log_fault
    priority: 1
    description: Protección prioritaria durante precarga.

  - from: ACTIVE.PRECHARGE
    event: ADC_UPDATE
    guard: precharge_voltage_reached
    to: ACTIVE.CLOSE_MAIN_CONTACTOR
    actions:
      - name: log_event
        args:
          event_id: PRECHARGE_COMPLETED
    priority: 20

  - from: ACTIVE.PRECHARGE
    event: ADC_UPDATE
    guard: no_fault
    to: ACTIVE.PRECHARGE
    internal: true
    actions:
      - update_measurements
      - monitor_precharge_progress
    priority: 100
    description: Transición interna; no ejecuta on_exit ni on_entry.

  - from: ACTIVE.PRECHARGE
    event: TIMEOUT
    to: FAULT
    actions:
      - name: set_fault_reason
        args:
          reason: PRECHARGE_TIMEOUT
      - log_fault
    priority: 5

  - from: ACTIVE.CLOSE_MAIN_CONTACTOR
    event: MAIN_CONTACTOR_CLOSED
    guard: main_contactor_feedback_ok
    to: ACTIVE.CHARGING_CC
    actions:
      - open_precharge_contactor
      - name: log_event
        args:
          event_id: MAIN_CONTACTOR_READY
    priority: 10

  - from: ACTIVE.CLOSE_MAIN_CONTACTOR
    event: TIMEOUT
    to: FAULT
    actions:
      - name: set_fault_reason
        args:
          reason: MAIN_CONTACTOR_TIMEOUT
      - log_fault
    priority: 5

  # -------------------------------------------------------------------------
  # Carga CC/CV
  # -------------------------------------------------------------------------

  - from: ACTIVE.CHARGING_CC
    event: ADC_UPDATE
    guard: current_too_high
    to: FAULT
    actions:
      - name: set_fault_reason
        args:
          reason: CHARGE_OVERCURRENT
      - log_fault
    priority: 1

  - from: ACTIVE.CHARGING_CC
    event: ADC_UPDATE
    guard: temperature_too_high
    to: FAULT
    actions:
      - name: set_fault_reason
        args:
          reason: OVERTEMPERATURE
      - log_fault
    priority: 2

  - from: ACTIVE.CHARGING_CC
    event: ADC_UPDATE
    guard: voltage_target_reached
    to: ACTIVE.CHARGING_CV
    actions:
      - name: log_event
        args:
          event_id: ENTER_CV_MODE
    priority: 20

  - from: ACTIVE.CHARGING_CC
    event: ADC_UPDATE
    guard: no_fault
    to: ACTIVE.CHARGING_CC
    internal: true
    actions:
      - update_measurements
      - run_current_control_loop
      - monitor_temperature
    priority: 100

  - from: ACTIVE.CHARGING_CV
    event: ADC_UPDATE
    guard: current_too_high
    to: FAULT
    actions:
      - name: set_fault_reason
        args:
          reason: CHARGE_OVERCURRENT
      - log_fault
    priority: 1

  - from: ACTIVE.CHARGING_CV
    event: ADC_UPDATE
    guard: temperature_too_high
    to: FAULT
    actions:
      - name: set_fault_reason
        args:
          reason: OVERTEMPERATURE
      - log_fault
    priority: 2

  - from: ACTIVE.CHARGING_CV
    event: ADC_UPDATE
    guard: charge_current_below_finish_threshold
    to: ACTIVE.BALANCING
    actions:
      - name: log_event
        args:
          event_id: ENTER_BALANCING
    priority: 20

  - from: ACTIVE.CHARGING_CV
    event: ADC_UPDATE
    guard: no_fault
    to: ACTIVE.CHARGING_CV
    internal: true
    actions:
      - update_measurements
      - run_voltage_control_loop
      - monitor_temperature
    priority: 100

  # -------------------------------------------------------------------------
  # Balanceo y finalización
  # -------------------------------------------------------------------------

  - from: ACTIVE.BALANCING
    event: BALANCING_COMPLETE
    to: DONE
    actions:
      - name: log_event
        args:
          event_id: CHARGE_COMPLETED
    priority: 20

  - from: ACTIVE.BALANCING
    event: TIMEOUT
    to: DONE
    actions:
      - name: log_event
        args:
          event_id: BALANCING_TIMEOUT_FINISHING_ANYWAY
    priority: 30
    description: En este ejemplo, el timeout de balanceo no se considera fallo crítico.

  - from: ACTIVE.BALANCING
    event: ADC_UPDATE
    guard: temperature_too_high
    to: FAULT
    actions:
      - name: set_fault_reason
        args:
          reason: OVERTEMPERATURE
      - log_fault
    priority: 2

  # -------------------------------------------------------------------------
  # Parada ordenada
  # -------------------------------------------------------------------------

  - from: ACTIVE
    event: STOP
    to: STOPPING
    actions:
      - name: log_event
        args:
          event_id: STOP_REQUESTED
    priority: 10
    description: Transición desde cualquier subestado de ACTIVE hacia parada ordenada.

  - from: STOPPING
    event: ADC_UPDATE
    guard: no_fault
    to: STOPPING
    internal: true
    actions:
      - monitor_output_shutdown
    priority: 100

  - from: STOPPING
    event: TIMEOUT
    to: IDLE
    actions:
      - open_main_contactor
      - open_precharge_contactor
      - name: log_event
        args:
          event_id: STOP_COMPLETED
    priority: 20

  # -------------------------------------------------------------------------
  # Fallos, reset y reintentos
  # -------------------------------------------------------------------------

  - from: FAULT
    event: RESET
    guard: fault_cleared && can_retry
    to: IDLE
    actions:
      - clear_faults
      - increment_retry_counter
      - name: log_event
        args:
          event_id: FAULT_RESET
    priority: 10

  - from: FAULT
    event: RESET
    guard: fault_cleared && cannot_retry
    to: LOCKED_OUT
    actions:
      - name: log_event
        args:
          event_id: LOCKOUT_ENTERED
    priority: 5

  # -------------------------------------------------------------------------
  # Transiciones globales de seguridad
  # -------------------------------------------------------------------------

  - from: "*"
    event: EMERGENCY_STOP
    to: FAULT
    actions:
      - disable_pwm
      - disable_balancing
      - open_precharge_contactor
      - open_main_contactor
      - name: set_fault_reason
        args:
          reason: EMERGENCY_STOP
      - log_fault
    priority: 0
    description: Transición global de máxima prioridad.

  - from: "*"
    event: FAULT_DETECTED
    to: FAULT
    actions:
      - disable_pwm
      - disable_balancing
      - open_precharge_contactor
      - open_main_contactor
      - name: set_fault_reason
        args:
          reason: FROM_EVENT_PAYLOAD
      - log_fault
    priority: 1
    description: Cualquier fallo detectado lleva a estado seguro.
```

---

## Notas sobre el ejemplo

### 1. Estados jerárquicos

El estado `ACTIVE` contiene subestados:

```text
ACTIVE.PRECHARGE
ACTIVE.CLOSE_MAIN_CONTACTOR
ACTIVE.CHARGING_CC
ACTIVE.CHARGING_CV
ACTIVE.BALANCING
```

Esto permite definir una transición común:

```yaml
- from: ACTIVE
  event: STOP
  to: STOPPING
```

Esa transición aplica desde cualquier subestado de `ACTIVE`.

---

### 2. Transiciones internas

Ejemplo:

```yaml
- from: ACTIVE.CHARGING_CC
  event: ADC_UPDATE
  guard: no_fault
  to: ACTIVE.CHARGING_CC
  internal: true
  actions:
    - update_measurements
    - run_current_control_loop
```

Al estar marcada como `internal: true`, no se ejecutan `on_exit` ni `on_entry` del estado.

---

### 3. Prioridades

Las transiciones de protección tienen prioridad menor numéricamente:

```yaml
priority: 1
```

Las transiciones normales tienen prioridad más baja:

```yaml
priority: 20
```

La regla usada es:

```text
menor número = mayor prioridad
```

---

### 4. Guards por expresión y por función

Guard por expresión:

```yaml
- name: current_too_high
  expression: charge_current > max_charge_current
```

Guard por función externa:

```yaml
- name: main_contactor_feedback_ok
  function: guard_main_contactor_feedback_ok
```

Esto permite que algunas condiciones sean generables directamente y otras queden como funciones implementadas por firmware.

---

### 5. Acciones parametrizadas

Ejemplo:

```yaml
- name: set_fault_reason
  args:
    reason: OVERTEMPERATURE
```

Un generador de C podría convertirlo en:

```c
action_set_fault_reason(ctx, FAULT_REASON_OVERTEMPERATURE);
```

---

### 6. Eventos con payload

Ejemplo:

```yaml
- name: ADC_UPDATE
  payload:
    - name: battery_voltage
      type: float
      unit: V
```

Esto permite generar estructuras de evento:

```c
typedef struct {
    float battery_voltage;
    float charge_current;
    float temperature_heatsink;
} HVChargerFSM_AdcUpdatePayload;
```

---

### 7. Eventos ignorados y diferidos

Evento ignorado:

```yaml
ignore:
  - ADC_UPDATE
```

Evento diferido:

```yaml
defer:
  - START
```

La diferencia es:

- `ignore`: el evento se descarta de forma explícita.
- `defer`: el evento se guarda para procesarlo más adelante.

---

### 8. Política de eventos no manejados

```yaml
unhandled_event_policy:
  behavior: log
  action: log_unhandled_event
```

Esto evita que el comportamiento ante eventos inesperados quede implícito.

---

### 9. Invariantes

Ejemplo:

```yaml
invariants:
  - pwm_enabled == false
```

Un generador puede convertir esto en asserts, checks de debug o tests automáticos.

---

### 10. Qué partes debería generar automáticamente una herramienta

A partir de este YAML se podrían generar:

- `enum` de estados.
- `enum` de eventos.
- Estructura de contexto.
- Estructuras de payload.
- Prototipos de guards.
- Prototipos de acciones.
- Dispatcher principal.
- Función de inicialización.
- Función de tick para timeouts.
- Tests unitarios básicos.
- Diagrama `.dot` o Mermaid.
- Documentación de comportamiento.
```

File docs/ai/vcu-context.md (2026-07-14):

# VCU-H11 AI Context

This file is the durable AI context for the Vehicle Control Unit firmware. Future agents should read it before planning or editing this repository, then update it whenever they learn stable VCU knowledge.

## Purpose

VCU-H11 is the Vehicle Control Unit firmware for Hyperloop UPV. In conversations it may also be called the Master. It targets the STM32H723ZGT6 custom H11 board and is built on ST-LIB.

The repository was created from `Hyperloop-UPV/template-project`, but template example code and example docs are not part of the VCU product surface.

## Legacy VCU Logic Reference

The previous VCU board codebase at `/Users/jsaegar/hyper-src/VCU-H10-V2` is a behavior reference only. It used an old ST-LIB API and should not be copied for H11 hardware access patterns.

Extracted H10-V2 business-logic docs live in `docs/vcu-logic/`. They describe the VCU as the vehicle master responsible for state-gated command arbitration, local brake/pump/sensor handling, telemetry, remote-board order forwarding, acknowledgement tracking, and faulting on unsafe conditions, lost required peers, emergency stop, or remote acknowledgement timeout.

Stable H10 behavior to preserve in H11 intent:

- Required peer connectivity gates normal operation.
- Orders should be validated against operational state before acting.
- Local fault/safety behavior includes SDC-open faulting, emergency-stop propagation, brake-on-fault intent, and tape/brake reed checks that need active-level and safety review before H11 implementation.

Current H11 product state machine:

- The explicit VCU states are `Idle`, `Connected`, `Maintenance`, `Precharging`, `HVActive`, `Ready`, `Propulsion`, `StaticLevitation`, `DynamicLevitation`, and `Fault`.
- `Idle` transitions to `Connected` only when the control station and required boards are connected. The current required peers are control station, HVBMS, and LCU. PCU connectivity is tracked but does not gate `Idle -> Connected`.
- `Connected` accepts high-level `Maintenance` and `Precharge` orders. `Stop` returns commandable non-idle modes to `Connected`. `Open contactors` opens contactors and returns non-Idle modes below propulsion/levitation to `Connected`.
- `Brake` is accepted from `Ready`, `Propulsion`, `StaticLevitation`, and `DynamicLevitation`. From active motion/levitation states it engages brakes and returns to `HVActive` while keeping contactors closed; active-mode exit actions still stop propulsion and/or levitation.
- `Precharging` sends the HVBMS precharge request (order ID 903) through `hvbms_tcp`.
- `Fault` is intentionally part of the current formal product state machine by explicit user request. ST-LIB protections and `FaultController` still provide the underlying fault trigger infrastructure.
- Current protection/diagnostic policy: SDC open faults, control-station disconnect faults outside `Idle`, and high pressure below 50 bar emits a warning. Brakes unbraked protection is currently sampled and published but temporarily does not fault the VCU while `DISABLE_BRAKE_UNBRAKED_PROTECTION` is enabled for bench testing.
- `tapes_reached` protection and ADJ measurement removed entirely (no tape input pin on H11).
- Flow sensors and NTC temperature sensors are not used in current firmware; their telemetry packets and sampling were removed from this version.

## Current Firmware Shape

- Main application entry: `Core/Src/main.cpp`.
- Main VCU facade: `Core/Inc/VCU.hpp`.
- Device requests, global runtime pointers, and app state: `Core/Inc/VCU_TYPES.hpp`.
- State machine skeleton: `Core/Inc/StateMachine/VCU_StateMachine.hpp`.
- Manual remote-board enum/order definitions: `Core/Inc/Communications/RemoteBoards.hpp`.
- Declarative operational FSM spec: `docs/vcu_state_machine.yaml`.
- Hardware pin aliases: `Core/Inc/Pinout/Pinout.hpp`.
- Packet schemas: `Core/Inc/Code_generation/JSON_ADE/boards/VCU/`.

Generated Ethernet comms bind the control-station UDP telemetry socket plus PCU, HVBMS, and LCU UDP sockets. The remote UDP sockets are needed because incoming state packets update the global `HeapPacket` values that the VCU uses for acknowledgement tracking.

The VCU ADJ defines only the control-station-facing orders and telemetry packets. Remote-board orders (to PCU, LCU, HVBMS) and incoming remote-board state packets are manually defined in `Core/Inc/Communications/RemoteBoards.hpp`. The auto-generated `OrderPackets` class from ADJ does not contain remote-board forwarding orders; the state machine uses `RemoteBoards::Start_SVPWM_to_pcu_order`, `RemoteBoards::Levitate_to_lcu_order`, etc. via the generated TCP sockets (`OrderPackets::pcu_tcp`, `OrderPackets::lcu_tcp`, `OrderPackets::hvbms_tcp`).

Remote board state enums are manually defined to match each remote board's ADJ measurements:
- HVBMS: `HVBMS_SM_State` (IDLE, READY_TO_PRECHARGE, PRECHARGING, ENERGIZED, FAULT) via packet ID 960
- PCU: `PCU_State` (Connecting, IDLE, Accelerating, Fault) via packet ID 553
- LCU: `LCU_Master_SM_State` (Connecting, Idle, Levitating, Current_Control, Debug, Fault) via packet ID 9520

VCU remote orders sent (defined in `RemoteBoards.hpp`):
- To HVBMS: FAULT (0), start_precharge (903), open_contactors (901)
- To PCU: Start_SVPWM (507), Stop_Motor (508)
- To LCU: Levitate (9010), Stop (9000)

ST-LIB TCP client sockets can be constructed before the Ethernet link has a
route to the remote board. Initial `tcp_connect()` failures such as lwIP
`ERR_RTE` must be treated as retryable by setting `pending_connection_reset`,
not as a startup panic, so VCU boot can continue while remote boards come up.
The VCU state machine should also call `reconnect()` on disconnected remote TCP
client sockets while refreshing peer connectivity.

Peer connection monitoring publishes a runtime `INFO` diagnostic on rising
edges when the control station, HVBMS, PCU, or LCU connects to the master. Once
a peer has connected, a later disconnect transitions the VCU to `Fault` with a
board-specific reason such as `HVBMS disconnected`, `LCU disconnected`, or
`PCU disconnected`.

Status LED behavior is driven by a 200 ms scheduled task. In `Idle`, while the
VCU is still waiting for required peers, `led_operational` blinks and
`led_connecting` stays off. Once required peers are connected, `led_operational`
stays on. Fault states turn on `led_fault` and turn off the other status LEDs.

VCU-H11 requires Ethernet. Do not support or maintain non-Ethernet VCU builds;
application code intentionally fails compilation when `STLIB_ETH` is not
defined.

For isolated VCU bench testing, the firmware supports a `SINGLE` compile mode.
Build it with the `board-debug-eth-ksz8041-single` preset while the nested ADJ
repository is on branch `vcu/single`. That ADJ branch removes remote-board
sockets and packets/orders, leaving only the control-station links and local VCU
telemetry/orders. In `SINGLE`, required peer connectivity means control-station
connectivity only, remote-board command forwarding is compiled out, and
precharge completion is simulated locally by marking contactors closed.

The build also supports simple Ethernet mock peer entry points selected with the
`VCU_APP_TARGET` CMake cache variable. `master` builds the normal VCU main,
`hvbms_mock` builds a Nucleo mock with IP `192.168.1.7`, and `lcu_mock` builds a
Nucleo mock with IP `192.168.1.4`. The mock firmwares now use manually defined
state enums and orders (matching the remote board ADJ definitions) since the mock
ADJ boards were removed in the final ADJ version. Mocks receive orders matching
the current remote-board order IDs (e.g., HVBMS mock receives precharge on 903,
open contactors on 901; PCU mock receives Start_SVPWM on 507, Stop_Motor on 508;
LCU mock receives Levitate on 9010, Stop on 9000). Mock state packets (960, 553,
9520) are sent to the VCU over the same packet IDs the real boards use.

ADJ measurements that represent VCU state-machine states should keep their
numeric wire type, currently `uint8`, and add `enumValues` in numeric order so
the control station can display labels. Remote board status fields are not part
of the VCU state machine and are currently not exposed as VCU measurements or
packets.

`VCU::update()` should keep servicing infrastructure each loop:

- `FaultController::check_transitions()`
- `Board::evaluate_protections()`
- `Diagnostics::Hub::flush()`
- `Scheduler::update()`

`docs/vcu_state_machine.yaml` describes the current H11 FSM in the formal format from `docs/fsm_format_spec.md`, and `docs/vcu_state_machine_diagram.md` renders the same flow as Mermaid.

## ST-LIB Board Conventions

Use the `ST_LIB::Board` type as the single application-level hardware registry.

Expected pattern:

1. Declare `inline constexpr` device request objects at namespace scope in `VCU_TYPES.hpp`.
2. Pass those requests to `using Board = ST_LIB::Board<...>` in `VCU.hpp`.
3. Call `Board::init()` once during `VCU::init()`.
4. Store runtime instance pointers from `Board::instance_of<request>()` only after `Board::init()`.
5. Access hardware through those ST-LIB instances, not through HAL directly.

Do not declare device requests inside functions. They must remain compile-time objects.

Use the most abstract ST-LIB object that matches the hardware role. For example, analog pressure sensors should be exposed through `LinearSensor<float>` fed by `ADCDomain` instances, NTC channels through `NTC`, and edge/interrupt sensors through `EXTIDomain`/`SensorInterrupt` where appropriate. Do not represent a higher-level sensor as a raw `DigitalInput` or `DigitalOutput` unless ST-LIB does not currently provide a better abstraction.

## Faults, Protections, Diagnostics

ST-LIB protections and diagnostics remain the mechanism for detecting and entering fault behavior. Current scaffold uses `ST_LIB::FaultPolicyNoMachine<on_fault_enter>`.

By explicit user request, the current VCU product FSM also exposes `Fault` as a formal state and telemetry value. Keep ST-LIB protection/fault policy as the trigger infrastructure; do not replace it with ad hoc HAL checks.

Relevant ST-LIB docs:

- `deps/ST-LIB/docs/protections-and-diagnostics.md`
- `deps/ST-LIB/docs/st-lib-board-contract.md`

## Naming

Firmware concepts must be in English. Prefer domain names that describe intent, not schematic abbreviations.

Current pinout naming examples:

- `cooling_pump_1` and `cooling_pump_2`, not `bomba_*`
- `electrovalve`, not `electrovalv`
- `pressure_regulator_out`, not `regulador_*`
- `brake_reset` and `brakes_status_input`
- `ntc_temperature_1` and `ntc_temperature_2`
- `sdc_closed`

The Altium schematic may use Spanish names or shortened net names. Convert those into clear English names in firmware.

## Pinout Facts

The current pinout was extracted from `docs/VCU_H11G.zip`, specifically `MCU.SchDoc`, cross-checked with `docs/Schematic PDF_[No Variations].pdf`.

`docs/VCU.ioc` is the current source for each MCU pin role. Confirmed roles:

- `PF0` and `PF1`: TIM23 input capture channels for flow sensors.
- `PF3` and `PF4`: ADC3 inputs for NTC temperature sensors.
- `PF11`: ADC1 input for `high_pressure`, the conditioned output of `Transductor_Alta_Presion` on connector `J13`. The schematic notes this as a ratiometric 0-5000 PSI transducer with a 0.5-4.5 V analog output scaled to about 0.367-3.3 V before the MCU.
- `PF12`: ADC1 input for `low_pressure`, the conditioned output of `Transductor_Baja_Presion` on connector `J14`. The schematic notes this as a ratiometric 0-10 bar sealed-gauge transducer with a 0.5-4.5 V analog output scaled to about 0.367-3.3 V before the MCU; because it is sealed gauge, the note says the real pressure range starts around 1.013 bar.
- `PA5`: ADC2 input for manual pressure regulator feedback sensing.
- `PA6`: not used by H11 firmware for regulator control. H11 uses a manual pressure regulator that is not commanded by firmware.
- `PF6`: EXTI6 input for `sdc_closed`.
- `PD14`: digital input for `brakes_status_input`.
- `PD15`: digital output for `brake_reset`.
- `PE13`: digital output for `cooling_pump_1`.
- `PE14`: digital output for `cooling_pump_2`.
- `PE15`: digital output for `electrovalve`.
- `PA8`: digital output for CAN silent mode.
- `PG3` and `PG4`: digital inputs for SDMMC write-protect and card-detect.
- `PG9` through `PG13`: digital outputs for info LEDs. The corrected Altium net on `PG11` is `LED_CONNECTING`, not `LED_FLASH`.

Current firmware-facing pin aliases:

| Concept | STM32 pin |
| --- | --- |
| `led_sleep` | `PG9` |
| `led_can` | `PG10` |
| `led_connecting` | `PG11` |
| `led_fault` | `PG12` |
| `led_operational` | `PG13` |
| `can_txd` | `PA12` |
| `can_rxd` | `PA11` |
| `can_silent` | `PA8` |
| `sdmmc_cmd` | `PD2` |
| `sdmmc_clk` | `PC12` |
| `sdmmc_d0` | `PC8` |
| `sdmmc_d1` | `PC9` |
| `sdmmc_d2` | `PC10` |
| `sdmmc_d3` | `PC11` |
| `sdmmc_card_detect` | `PG4` |
| `sdmmc_write_protect` | `PG3` |
| `flow_1` | `PF0` |
| `flow_2` | `PF1` |
| `ntc_temperature_1` | `PF3` |
| `ntc_temperature_2` | `PF4` |
| `high_pressure` | `PF11` |
| `low_pressure` | `PF12` |
| `sdc_closed` | `PF6` |
| `cooling_pump_1` | `PE13` |
| `cooling_pump_2` | `PE14` |
| `electrovalve` | `PE15` |
| `pressure_regulator_out` | `PA5` |
| `brake_reset` | `PD15` |
| `brakes_status_input` | `PD14` |

H11 does not use firmware-controlled pressure regulation. Do not request `PA6` / `TIM13_CH1` as a regulator PWM device, do not expose a set-regulator order, and do not publish commanded regulator duty. The pressure regulator is manual; firmware may only observe its feedback through `pressure_regulator_out` on `PA5` / `ADC2_INP19`.

Ethernet RMII is intentionally not listed in `Pinout.hpp`. Use ST-LIB pinset selection instead.

For VCU board Ethernet with KSZ8041, use:

```cpp
ST_LIB::EthernetDomain::PINSET_H11
```

`PINSET_H11` includes H11 RMII pins and no RXER pin. The current VCU H11 board
uses the KSZ8041 PHY path; the LAN8700 presets are not the correct hardware
target for this board.

## Build And Verification

Prefer the local CLI:

```bash
./hyper build main --preset board-debug-eth-ksz8041 --board-name VCU
```

Known passing checks:

- `./hyper build main --preset board-debug-eth-ksz8041 --board-name VCU`
- `./hyper build main --preset nucleo-debug-eth-hvbms-mock --board-name VCU`
- `./hyper build main --preset nucleo-debug-eth-lcu-mock --board-name VCU`
- `python3 -m py_compile hyper`

Known intentional failure:

- `./hyper build main --preset board-debug --board-name VCU` fails because
  `STLIB_ETH` is not defined.

When modifying ADJ files under `Core/Inc/Code_generation/JSON_ADE`, run the ADJ validator before handoff. The validator depends on `jsonschema`; install the pinned tester requirements into the repository virtual environment when needed:

```bash
.venv/bin/python -m pip install -r Core/Inc/Code_generation/JSON_ADE/.github/workflows/scripts/adj-tester/requirements.txt
```

Run the validator from the ADJ root with the repository virtual environment:

```bash
cd Core/Inc/Code_generation/JSON_ADE
../../../../.venv/bin/python .github/workflows/scripts/adj-tester/main.py
```

The validator checks schema validity and project consistency such as unused measurements. If ADJ packets or orders are removed for a test branch, trim `VCU_measurements.json` to match the remaining packet/order variables or the validator will fail.

Do not restore `Core/Src/Runes/generated_metadata.cpp` after builds. The user explicitly requested that generated metadata stay as generated.

## Altium And Hardware Inputs

Current hardware inputs in `docs/`:

- `Schematic PDF_[No Variations].pdf`
- `VCU_H11G.zip`
- `Gerber for PCB.PcbDoc.zip`
- `STEP_[No Variations] for PCB.PcbDoc.step`
- `Assembly Drawings_[No Variations].pdf`
- `BOM_[No Variations].csv`

The Altium source archive is more authoritative than PDF OCR/text extraction. Use the `.SchDoc` records for pin/net extraction when possible.

## Open Decisions

These need confirmation before implementing more runtime behavior:

- Active level and safe default for every output.
- Pull-up/pull-down requirements for digital inputs.
- Sensor calibration and units for pressure.
- Protection thresholds and diagnostic IDs.
- Whether brake fault should remain a polled protection only or also become EXTI-triggered.

## Maintenance Protocol

Update this file when a durable fact becomes known. Good updates include:

- New confirmed pin mappings or active levels.
- Chosen ST-LIB device request patterns.
- Confirmed VCU operational states and transitions.
- Protection and diagnostic policies.
- Build, flash, debug, or hardware validation workflows that were actually run.
- ADJ validation workflows, especially if the command or required environment changes.
- User preferences that affect future work.

Do not add transient command output, speculative assumptions, or one-off debugging notes. If a fact is inferred rather than confirmed, label it as inferred and keep it in `Open Decisions` until confirmed.

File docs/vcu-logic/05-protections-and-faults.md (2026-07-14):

# Protections and Faults

H11 uses ST-LIB protections, diagnostics, and `FaultPolicyNoMachine` as the
fault trigger infrastructure. The product FSM also exposes `Fault` as a formal
state and telemetry value.

## Active Fault Triggers

| Trigger | Type | Behavior |
| --- | --- | --- |
| `sdc_closed == false` | ST-LIB protection and FSM check | Enters `Fault`. |
| `brakes_status == UNBRAKED` | ST-LIB protection and FSM check | Enters `Fault`. |
| `tapes_reached == true` | ST-LIB protection and FSM check | Enters `Fault`. |
| Control station disconnect after required peers were connected | FSM check | Enters `Fault` outside `Idle`. |
| `FAULT` order | Operator/order path | Enters `Fault` and propagates fault. |
| `Emergency stop` order | Operator/order path | Enters `Fault` and propagates fault. |
| Remote order send failure | Runtime fault path | Calls `FAULT(...)`. |

`tapes_reached` is currently a formal software signal. H11 has no tape input pin
defined in `Pinout.hpp` yet, so the protection is ready but needs a hardware or
remote-data source to set the variable.

## Warnings

| Condition | Behavior |
| --- | --- |
| `high_pressure < 50 bar` | Emit a non-fatal warning. |

The pressure warning is intentionally not a fault. The current implementation
uses the high-pressure sensor because the low-pressure sensor range is not
compatible with a 50 bar threshold.

## Fault Entry Actions

On fault entry, VCU currently:

- exposes the product FSM state as `Fault`;
- turns off operational and connecting LEDs;
- turns on the fault LED;
- disables both cooling pumps;
- disables the electrovalve;
- marks contactors open and sends a best-effort open-contactors order when the
  HVBMS socket is connected;
- engages the brake;
- synchronizes telemetry.

`open_sdc` remains a formal action only. H11 currently exposes `sdc_closed` as
an input/protection, not as a controllable output.

## Open Safety Work

- Wire the real tape/end-of-track source into `tapes_reached`.
- Confirm active levels for `brakes_status`, `sdc_closed`, and the future tape
  signal on hardware.
- Define pressure, temperature, flow, and remote-acknowledgement thresholds if
  they should become warnings or faults.
- Assign final diagnostic IDs/severities if the diagnostics backend requires
  stable IDs.

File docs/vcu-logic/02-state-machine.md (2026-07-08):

# State Machine

The current H11 VCU state machine is an explicit product FSM implemented in
`Core/Inc/StateMachine/VCU_StateMachine.hpp` and specified formally in
`docs/vcu_state_machine.yaml`.

## States

| State | Meaning | Entry behavior |
| --- | --- | --- |
| `Idle` | Safe initial state waiting for required communication links. | Brake, open contactors, publish state. |
| `Connected` | Required links are connected and the VCU waits for high-level orders. | Brake, open contactors, publish state. |
| `Manteinance` | Maintenance mode. The spelling follows the current order/state contract. | Unbrake, publish state. |
| `Precharging` | Precharge has been requested. | Send the formal HVBMS precharge request, publish state. |
| `HVActive` | High voltage is active. | Publish state. |
| `Ready` | Vehicle is unbraked and ready for propulsion or levitation mode selection. | Unbrake, publish state. |
| `Propulsion` | Propulsion mode. | Start propulsion, publish state. |
| `StaticLevitation` | Static levitation mode. | Start static levitation, publish state. |
| `DynamicLevitation` | Dynamic levitation mode. | Start dynamic levitation, publish state. |
| `Fault` | Faulted safe state. | Open SDC formally, turn on fault LED, propagate fault, open contactors, brake, publish state. |

`open_sdc` is currently formal only: H11 exposes `sdc_closed` as an input and
protection, not as a controllable output.

## Required Links

`Idle` transitions to `Connected` when the VCU is connected to:

- control station;
- HVBMS;
- PCU;
- LCU.

The precharge flow is named as HVBMS-facing in the formal FSM. The current code
uses the existing high-voltage remote link/state packet until a dedicated HVBMS
socket and state packet are defined.

## Transitions

| From | To | Trigger |
| --- | --- | --- |
| `Idle` | `Connected` | Required links are connected. |
| `Connected` | `Manteinance` | `MANTEINANCE` order. |
| `Connected` | `Precharging` | `Precharge` order. |
| `Manteinance` | `Connected` | `Stop` order. |
| `Precharging` | `Connected` | `Stop` order. |
| `Precharging` | `HVActive` | Precharge completion from the high-voltage board. |
| `HVActive` | `Connected` | `Stop` order. |
| `HVActive` | `Ready` | `Unbrake` order. |
| `Ready` | `Connected` | `Stop` order. |
| `Ready` | `HVActive` | `Brake` order. |
| `Ready` | `Propulsion` | `Propulsion` order. |
| `Ready` | `StaticLevitation` | `Static levitation` order. |
| `Ready` | `DynamicLevitation` | `Dynamic levitation` order. |
| `StaticLevitation` | `DynamicLevitation` | `Dynamic levitation` order. |
| `Propulsion` | `HVActive` | `Brake` order. Brakes and keeps contactors closed. |
| `StaticLevitation` | `HVActive` | `Brake` order. Brakes and keeps contactors closed. |
| `DynamicLevitation` | `HVActive` | `Brake` order. Brakes and keeps contactors closed. |
| `Propulsion` | `Connected` | `Stop` order. |
| `StaticLevitation` | `Connected` | `Stop` order. |
| `DynamicLevitation` | `Connected` | `Stop` order. |
| Any state | `Fault` | Protection trigger or control-station disconnect after connection. |

The `Stop` exits from `Propulsion`, `StaticLevitation`, and
`DynamicLevitation` are included so their exit actions can run:

- exiting `Propulsion` stops propelling;
- exiting `StaticLevitation` stops levitating;
- exiting `DynamicLevitation` stops propelling and levitating.

The `Brake` exits from those same active modes run the same active-mode exit
actions and engage the brake, but transition to `HVActive` without opening
contactors.

## Active-Mode Orders

Low-level propulsion orders are only forwarded in `Propulsion` and
`DynamicLevitation`.

Low-level levitation orders are only forwarded in `StaticLevitation` and
`DynamicLevitation`.

## Fault Handling

ST-LIB protections and `FaultController` remain the trigger infrastructure.
The formal VCU FSM also exposes `Fault` as a state and telemetry value. Fault
entry applies the safe-output policy currently implemented by the VCU:

- turn on fault LED;
- propagate fault to remote boards when connected;
- request contactor opening;
- brake;
- synchronize telemetry.

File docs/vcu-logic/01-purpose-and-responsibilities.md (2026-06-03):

# Purpose and Responsibilities

## Overall Goal

The Vehicle Control Unit is the master controller for the pod. Its goal is to keep the vehicle in a coherent, safe operational mode while coordinating operator commands, local VCU hardware, and remote boards.

The VCU is responsible for deciding whether a command is allowed now. When a command belongs to another board, the VCU forwards it only from valid states, waits for the remote board to report the expected result, and faults if the acknowledgement does not arrive in time.

## Responsibilities

### Vehicle Supervision

The VCU owns the top-level view of vehicle readiness:

- whether required network peers are connected;
- whether the pod is idle, energized, ready to move, in demonstration/run behavior, or in recovery;
- whether contactors are considered closed;
- whether brakes are active;
- whether SDC and emergency tape signals are acceptable;
- whether a remote command has completed.

### Command Arbitration

Incoming orders are not executed blindly. The H10 logic follows this pattern:

1. A packet callback stores requested arguments and raises a command flag.
2. The periodic VCU update checks the flag.
3. The command handler verifies the current operational state.
4. If the command is local, the VCU acts locally.
5. If the command belongs to another board, the VCU sends a remote order.
6. The VCU waits for the remote board's reported state.
7. If the expected state is observed, the flag is cleared and local VCU state is updated.
8. If the expected state is not observed before timeout, the VCU enters fault handling and propagates the fault.

### Local Hardware Control

The H10 VCU directly controlled or read:

- brake actuator command;
- brake reed sensors;
- emergency tape input and tape-enable output;
- pressure regulator command outputs;
- pressure-regulator feedback inputs;
- cooling pump outputs;
- flow inputs;
- SDC input;
- pressure sensors;
- status LEDs.

The H11 hardware differs, but these responsibilities still define the VCU behavior that should be implemented. H11 specifically does not command a pressure regulator from firmware: regulator pressure is set manually outside the VCU, and firmware only keeps the available regulator-pressure feedback as telemetry.

### Remote Board Coordination

The H10 logic treats these boards as coordinated peers:

| Board | VCU responsibility |
| --- | --- |
| Control station | Receive operator orders and send VCU telemetry. |
| HVBMS | Request contactor close/open and wait for HVBMS state acknowledgement. |
| PCU | Forward run and motor-control orders and wait for propulsion/stop state acknowledgement. |
| LCU | Forward levitation and booster orders and wait for levitation/booster state acknowledgement. |
| BMSL, BCU, BLCU | Referenced by legacy code, but not fully active in the inspected H10 snapshot. |

### Telemetry

The H10 VCU reported:

- general and operational states;
- brake reed states and combined reed status;
- flow inputs;
- H10 high, regulator, brake, and capsule pressure values;
- H11 high, low, and manual-regulator feedback pressure values;
- tape enable and emergency tape states;
- SDC state;
- selected remote-board states;
- VCU recovery status.

H11 currently has a smaller generated telemetry set. The H10 list is the broader behavior reference.

### Safety and Fault Handling

The H10 VCU faults on connectivity loss, unsafe brake/tape/SDC conditions, explicit emergency stop, and failed remote acknowledgements. On fault, it changes LED indication and schedules a brake action.

In H11, this behavior should be implemented through the ST-LIB fault, protection, diagnostics, and scheduler APIs. `Fault` should not be added as an application operational state.

## Non-Responsibilities

The VCU is not the low-level controller for every subsystem:

- HVBMS owns the physical contactor actuation.
- PCU owns propulsion and motor control.
- LCU owns levitation and booster behavior.
- The control station owns operator UI and command generation.

The VCU's role is to authorize, sequence, observe, and fail safe.

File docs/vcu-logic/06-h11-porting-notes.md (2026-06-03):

# H11 Porting Notes

## Port Intent, Not Old Infrastructure

The H10 code is valuable for business logic only. H11 uses a newer ST-LIB with a different architecture. Do not preserve these old implementation details:

- direct construction of legacy `PWM`, `DigitalOutput`, `DigitalSensor`, or `LinearSensor` objects outside the H11 `Board` contract;
- H10 `ProtectionManager` state-machine linkage style;
- raw `HeapPacket` and `HeapOrder` registration if generated H11 packet code can express the same behavior;
- a general `Fault` application state.

Preserve the intent:

- state-gated command acceptance;
- local brake, manual-regulator feedback, pump, SDC, flow, pressure, and LED behavior;
- remote order forwarding with acknowledgement;
- telemetry cadence;
- fault on unsafe conditions, lost required peers, emergency stop, and failed acknowledgements.

## Suggested H11 Modules

The H10 classes map naturally to these H11 responsibilities:

| H10 concept | H11 implementation direction |
| --- | --- |
| `VCU` facade | Keep `VCU::init()` and `VCU::update()` as the top-level lifecycle. |
| `VCU_SM` | Implement normal operational modes in `StateMachine/VCU_StateMachine.hpp`; keep fault out of the operational enum. |
| `Comms` | Use generated packet/order code plus a small dispatcher for state-gated order handling. |
| `Actuators` | Use ST-LIB `Board` instances and small domain functions for pumps, brake output, and sensor reads. H11 must not command regulator pressure. |
| `Brakes` | Use ST-LIB output/input/interrupt abstractions and a clear brake policy with confirmed active levels. |
| `Leds` | Keep LED state helpers or scheduled tasks using H11 LED aliases. |
| H10 protections | Convert to ST-LIB protections, diagnostics, `FaultController`, and fault-policy callbacks. |

## Implementation Sequence

1. Define required remote peers for H11. At minimum H10 required control station, HVBMS, and PCU before `Operational`.
2. Implement operational states without a `Fault` enum value: `Idle`, `EndOfRun`, `Energized`, `Ready`, `Demonstration`, `Recovery`.
3. Add clear state transition predicates for contactors, brakes, recovery, and demonstration bitfield.
4. Add local brake behavior after active levels are confirmed. Keep regulator pressure manual and firmware-observed only.
5. Add order handlers that only raise flags or enqueue commands from packet callbacks.
6. Add dispatcher checks that enforce allowed states before acting.
7. Add remote acknowledgement tracking and timeout diagnostics.
8. Add ST-LIB protections for SDC, brake fault, pressure limits, temperature limits, and any remote-ack timeout faults.
9. Extend generated telemetry to cover the full VCU behavior when measurements and units are confirmed.

## Naming Translation

Prefer H11 English names over H10 names:

| H10 name | H11-style concept |
| --- | --- |
| `Potencia_refri` | Cooling pump power or cooling pump command. |
| `PresionAlta` | High pressure. |
| `PresionRegulador` | Manual-regulator pressure feedback. |
| `PresionFrenos` | Brake pressure. |
| `PresionCapsula` | Capsule pressure. |
| `Sdc` | SDC closed or SDC state. |
| `breaks_first_time` | Brake first-time flag. |
| `All_reeds` | All brake reeds active. |

## Current H11 Implementation Notes

The H11 code now implements the major H10 business-logic gaps deliberately rather than copying old infrastructure:

- command dispatchers exist for brake, unbrake, contactors, pumps, recovery, and remote-board commands;
- operational state transitions are derived from contactor status, brake status, recovery request, and the demonstration bitfield;
- generated sockets cover the control station, HVBMS, PCU, LCU, and BCU paths used by the dispatcher;
- remote acknowledgements are tracked for HVBMS, PCU, LCU, and booster behavior;
- H11 does not expose pressure-regulator control because a manual regulator is used;
- fault entry turns local outputs to their safe firmware-owned states and commands the brake active.

The remaining open decisions are calibration and hardware-validation items:

- pressure and temperature calibration still use placeholders;
- flow measurement wrapper is not finalized;
- fault/protection thresholds and diagnostic IDs are still open.

These docs define the intended behavior and the known H11 differences from the H10 reference.

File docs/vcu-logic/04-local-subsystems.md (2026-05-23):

# Local Subsystems

## Actuators

The H10 `Actuators` class groups local non-brake hardware: pressure regulators, pumps, flow inputs, SDC input, and pressure sensors.

### Pressure Regulator

H10 had two regulator command outputs and two regulator feedback inputs.

- Each regulator command used PWM.
- PWM frequency was set to 30 kHz.
- Requested pressure was clamped to maximum `6`.
- Pressure command was converted to duty with `pressure * (100 / 6)`.
- Regulator pressure commands were included in telemetry.

H11 intentionally does not control regulator pressure from firmware. A manual regulator will be used instead, so the H11 firmware must not request the old regulator PWM pin, expose a set-regulator order, or publish a commanded-regulator duty. The available regulator feedback ADC may still be read and published so operators can observe the manually set pressure.

### Cooling Pumps

H10 exposed two pump outputs:

- pump 1 represented one selected cooling circuit;
- pump 2 represented the other selected cooling circuit;
- the old code treated duty `100` as on and all other duty values as off.

The packet name `Potencia_refri` should be translated to an English firmware concept such as cooling pump power or cooling pump command.

### Flow Inputs

H10 read two flow inputs as digital sensors. H11 pinout assigns the flow sensors to timer input-capture channels, so H11 should model them as measured pulse/frequency sources rather than simple digital states once the ST-LIB abstraction is selected.

### SDC Input

The SDC signal is a safety-critical input. In H10, the general state machine faults from `Operational` when the SDC value is false/open.

H11 already models SDC through an EXTI-backed interrupt/sensor path. Preserve the behavior that an open SDC is not compatible with normal operation.

### Pressure Sensors

H10 tracked four pressure values:

| Value | H10 calibration note |
| --- | --- |
| High pressure | Linear gain `0.00763`, offset `0.318`. |
| Regulator pressure | Linear gain `0.256`, offset `0.375`. |
| Brake pressure | Linear gain `0.256`, offset `0.375`. |
| Capsule pressure | Declared as uncharacterized and not read in the inspected H10 loop. |

H11 currently tracks high pressure, low pressure, and manual-regulator feedback. Final calibration and units remain open decisions.

## Brakes

The H10 `Brakes` class owns the local brake actuator, reed sensors, emergency tape input, and tape-enable output.

### Brake Actuator

H10 behavior:

- startup initializes the brake actuator output off and considers brakes active;
- `brake()` turns the actuator output off and sets `Active_brakes = true`;
- `unbrake()` turns the actuator output on and sets `Active_brakes = false`;
- the first brake command clears a `breaks_first_time` flag used by fault logic.

The active level must be confirmed on H11 before implementing. The important behavior is that fault handling commands the brake into the safe braking condition.

### Reed Sensors

H10 pinout declared eight reed pins, but the inspected brake code reads four:

- reed 1;
- reed 2;
- reed 3;
- reed 4.

It computes `All_reeds` as the logical AND of the four read values. The general state machine faults when `All_reeds` is true after the first brake sequence has occurred. The safety intent of this condition should be confirmed before porting because the old code includes a warning comment near that transition.

### Emergency Tape and Tape Enable

H10 has:

- one emergency tape input;
- one tape-enable output;
- a cached tape-enable status used by the state machine.

The operational state machine changes tape behavior:

- entering `Ready` or `Demonstration` disables tapes in H10 naming;
- exiting `Ready` or `Demonstration` enables tapes;
- entering `Recovery` enables tapes.

The H10 function names and pin states are legacy wiring concepts. Porting should start from the intended safety behavior, not the old active-level names.

## LEDs

The H10 LED logic is simple vehicle-status feedback:

| Mode | LED behavior |
| --- | --- |
| Connecting | Operational LED toggles every 500 ms. |
| Operational | Operational LED is solid on. |
| Fault | Fault LED toggles every 500 ms. |

Other LEDs were declared but not meaningfully used in the inspected H10 logic.

H11 has separate sleep, CAN, connecting, fault, and operational LED aliases. Preserve the state indication intent with the H11 LED names.

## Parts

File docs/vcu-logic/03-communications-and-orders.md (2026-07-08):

# Communications and Orders

## Network Role

The H10 VCU is both a server for operator/control-station commands and a client of remote vehicle boards. It also sends UDP telemetry.

| Endpoint | H10 address or port | Purpose |
| --- | --- | --- |
| VCU | `192.168.1.3` | Local board IP. |
| Control station | `192.168.0.9` | Operator endpoint for telemetry. |
| Control station TCP | local port `50500` | Receives operator orders. |
| Control station UDP | local and remote port `50400` | Sends VCU telemetry. |
| PCU | `192.168.1.5`, local TCP port `50501`, UDP port `50402` | Propulsion and motor-control orders; UDP state feedback. |
| HVBMS | `192.168.1.7`, local TCP port `50502`, UDP port `50403` | Contactor orders; UDP state feedback. |
| BMSL | `192.168.1.254`, ports declared but commented in H10 startup. | Battery management reference. |
| LCU | `192.168.1.4`, local TCP port `50504`, UDP port `50405` in H11. H10 had these ports declared but commented in the inspected startup. | Levitation and booster orders; UDP state feedback. |
| BCU | `192.168.2.17`, port declared but not fully active in H10 startup. | Booster reference. |

The inspected H10 snapshot only required control station, HVBMS, and PCU TCP connections for `Connecting -> Operational`.

## Order Handling Pattern

Most orders use the same high-level flow:

1. A `HeapOrder` is registered with an ID, callback, and optional argument storage.
2. The callback records arguments and sets an order flag.
3. `Comms::update()` calls `check_orders()`.
4. The matching `check_*_order()` function verifies the current operational state.
5. The command is either executed locally or sent to a remote board.
6. For remote commands, the VCU waits until a remote-state variable matches the expected acknowledgement.
7. On success, the VCU clears sent flags, clears the order flag, and updates local state or the demonstration bitfield.
8. On timeout, the VCU calls fault propagation.

This split is important: packet callbacks should stay short and should not bypass state gating.

## Local Orders

| Order | ID | Behavior |
| --- | ---: | --- |
| `FAULT` | 0 | Enters `Fault` and propagates fault handling. |
| `Cooling pump power` | 33 | Selects pump 1 or 2 and applies the requested pump duty. Duty `100` turns the selected pump on and any other value turns it off. |
| `MANTEINANCE` | 34 | `Connected -> Manteinance`. The spelling follows the current order contract. |
| `Precharge` | 35 | `Connected -> Precharging`. |
| `Stop` | 36 | Returns commandable non-idle modes to `Connected`, running active-mode exit actions. |
| `Propulsion` | 38 | `Ready -> Propulsion`. |
| `Static levitation` | 39 | `Ready -> StaticLevitation`. |
| `Dynamic levitation` | 40 | `Ready` or `StaticLevitation -> DynamicLevitation`. |
| `Brake` | 43 | `Ready`, `Propulsion`, `StaticLevitation`, or `DynamicLevitation -> HVActive`; engages brakes and keeps contactors closed. |
| `Unbrake` | 52 | `HVActive -> Ready` and releases brakes through `Ready` entry. |
| `Emergency stop` | 55 | Enters `Fault` and propagates fault handling. |

## Forwarded Orders

| Domain | Operator order | Remote order ID | Required state | Behavior |
| --- | --- | ---: | --- | --- |
| High-voltage link | Precharge | 902 | `Precharging` entry | Sends the formal HVBMS precharge request over the existing high-voltage remote link until a dedicated HVBMS socket exists. |
| HVBMS | Open contactors | 901 | `Idle`, `Connected`, `Fault`, and stop-to-connected entry paths | Best-effort safe contactor-open request. |
| PCU | Runs | 1000 | `Propulsion`, `DynamicLevitation` | Forwarded as a propulsion-specific order. |
| PCU | SVPWM | 1001 | `Propulsion`, `DynamicLevitation` | Forwarded as a propulsion-specific order. |
| PCU | Stop motor | 1002 | Exit from `Propulsion` or `DynamicLevitation` | Stops propelling. |
| PCU | Current control | 1003 | `Propulsion`, `DynamicLevitation` | Forwarded as a propulsion-specific order. |
| PCU | Speed control | 1004 | `Propulsion`, `DynamicLevitation` | Forwarded as a propulsion-specific order. |
| PCU | Motor brake | 1005 | `Propulsion`, `DynamicLevitation` | Forwarded as a propulsion-specific order. |
| LCU | Levitation | 9989 | `StaticLevitation`, `DynamicLevitation` | Forwarded as a levitation-specific order. |
| LCU | Stop levitation | 9993 | Exit from `StaticLevitation` or `DynamicLevitation` | Stops levitating. |

## Telemetry Packets

The H10 code registers these outgoing packets:

| Packet | H10 ID | Variables |
| --- | ---: | --- |
| `States` | 249 | General state, operational state. |
| `Flow` | 250 | Flow 1, flow 2. |
| `Reeds` | 251 | Reed 1 through reed 4, all-reeds status. |
| `Regulator` | 252 | H10 regulator 1 pressure command, regulator 2 pressure command. Not used on H11. |
| `Pressure` | 253 | H10 high pressure, regulator pressure, brake pressure, capsule pressure. H11 publishes high pressure, low pressure, and manual-regulator feedback. |
| `Tapes` | 254 | Tape-enable status, tape emergency input. |
| `Sdc` | 255 | SDC state. |
| `hvbms_state` | 941 | Last known HVBMS state. |
| `lcu_state` | 63 | Vertical and horizontal LCU states. |
| `pcu_state` | 64 | Last known PCU state. |
| `vcu_state` | 65 | Recovery status. |

The main telemetry send path transmits local VCU telemetry to the control station over UDP. It also sends the VCU state packet to the PCU UDP socket.

## Command Gating Summary

| Command group | Allowed operational states |
| --- | --- |
| MANTEINANCE, Precharge | `Connected`. |
| Stop | `Manteinance`, `Precharging`, `HVActive`, `Ready`, `Propulsion`, `StaticLevitation`, `DynamicLevitation`. |
| Unbrake | `HVActive`. |
| Brake | `Ready`, `Propulsion`, `StaticLevitation`, `DynamicLevitation`. |
| Propulsion, Static levitation, Dynamic levitation | `Ready`; dynamic levitation is also accepted from `StaticLevitation`. |
| Propulsion-specific low-level orders | `Propulsion`, `DynamicLevitation`. |
| Levitation-specific low-level orders | `StaticLevitation`, `DynamicLevitation`. |
| Emergency stop, FAULT | Always enter `Fault`. |

## Timeout Behavior

The current explicit H11 FSM does not use the old demonstration-bitfield remote
acknowledgement timeouts. Precharge completion is inferred from the existing
high-voltage state packet until a dedicated HVBMS acknowledgement is defined.

Before adding timeout-based faulting back, validate the timing against real
network latency, actuator response, and safety requirements.

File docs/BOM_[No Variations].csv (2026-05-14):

Name | Description | Designator | Part Number | Price | Qty
Test point 1.2mm | 1.2mm Test point | +5V, +12V, P1, P2, RX1, T1, T2, T3, T4, TP1, TP2, TP3, TP4, TP5, TP6, TP7, TP8, TP9, TP10, TP11, TP12, TP13, TP14, TP15, TP16, TP17, TP18, TP19, TP20, TP21, TP22, TP23, TP24, TP25, TP26, TP27, TP28, TP29, TP30, TP31, TP32, TP33, TP34, TP35, TP36, TP37, TP38, TP39, TP40, TP41, TP42, TP43, TP44, TP45, TP46, TP47, TP48, TP49, TP50, TP51, TP52, TP53, TP54, TP55, TX1 |  |  | 65
0.1 µF | CAP CER 0.1UF 50V X7R 0603 | C1, C4, C5, C6, C7, C8, C9, C10, C11, C12, C13, C14, C15, C23, C41, C66, C67, C69, C72, C77, C82, C85, C86, C103, C104 | TDK CGA3E2X7R1H104K080AE, | 1.66721 | 25
10 µF | CAP CER 10UF 50V X7R 1206 | C2, C40 | Samsung Electro-Mechanics CL31B106KBHNNNE, | 0.70198 | 2
4.7 µF | CAP CER 4.7UF 50V X7R 1206 | C3 | Samsung Electro-Mechanics CL31B475KBHNFNE | 0.29249 | 1
4700 pF | CAP CER 0603 4.7NF 16V X7R 10% | C16 | Yageo Group C0603C472K4RECAUTO | 0.1404 | 1
2.2 µF | CAP CER 2.2UF 50V X7R 1206 | C17, C18 | Samsung Electro-Mechanics CL31B225KBHNFNE, | 0.49139 | 2
12pF | CAP CER 12PF 50V C0G/NP0 0603 | C19, C21 |  |  | 2
6.8 pF | CAP CER 6.8PF 50V C0G/NPO 0603 | C20, C22 | Yageo Group CC0603CRNPO9BN6R8, | 0.1872 | 2
10 µF | CAP CER 10UF 16V X5R 1206 | C24, C39 | TAIYO YUDEN EMK316BJ106MD-T, | 0.56159 | 2
22 µF | CAP CER 22UF 16V X5R 1206 | C25, C31 | Samsung Electro-Mechanics CL31A226KOCLFNC, | 0.98278 | 2
0.1 µF | CAP CER 0.1UF 50V X7R 0603 | C26, C27, C28, C29, C30, C32, C33, C34, C37, C45, C46 | Yageo Group C0603C104K5RAC7411, | 0.60488 | 11
1 µF | CAP CER 1UF 16V X7R 0603 | C35, C38 | Yageo Group C0603C105K4RACAUTO, | 0.25739 | 2
100 pF | CAP CER 100PF 50V C0G/NP0 0603 | C36 | Yageo Group C0603C101K5GACAUTO | 0.1287 | 1
47 pF | CAP CER 47PF 50V C0G/NP0 0603 | C42, C44 | Wurth Elektronik 885012006055, | 0.1872 | 2
4700pF | CAP CER 4700PF 50V X7R 0603 | C43 |  |  | 1
0.1 µF | CAP CER .1UF 100V X7R 0603 | C47, C54 |  |  | 2
1200 pF | CAP CER 1200PF 100V X7R 0603 | C48 | Yageo Group C0603C122K1RACTU | 0.30419 | 1
2.2µF | CAP CER 2.2UF 100V X7R 1206 | C49, C50, C56, C57 |  |  | 4
47 pF | CAP CER 56PF 250V C0G/NP0 0603 | C51 | Murata GQM1875C2E560JB12D | 0.35099 | 1
22µF | CAP CER 22UF 25V X5R 1206 | C52, C53, C59, C60 |  |  | 4
2200pF | CAP CER 2200PF 50V C0G/NP0 0603 | C55 |  |  | 1
56 pF | CAP CER 56PF 250V C0G/NP0 0603 | C58 | Murata GQM1875C2E560JB12D | 0.35099 | 1
10 µF | CAP CER 10UF 25V X7R 1206 | C61, C62 | Yageo Group C1206X106J3RACAUTO, | 3.29932 | 2
0.1 µF | CAP CER 0.1UF 50V X7R 0603 | C63, C73, C75, C80, C83 | Holystone C0603X104K050T, | 0.38609 | 5
1 µF | CAP CER 1UF 50V X7R 1206 | C64, C74, C84, C87, C91, C95, C98 | Yageo Group C1206C105K5RACAUTO, | 1.93045 | 7
3300pF | CAP CER 3300PF 50V X7R 0603 | C65, C68 |  |  | 2
1500 pF | CAP CER 1500PF 50V X7R 0603 | C76, C81 | TDK CGA3E2X7R1H152K080AA, | 0.1872 | 2
0.1 µF | CAP CER 0.1UF 16V X7R 0603 | C88, C89, C90, C92, C93, C94, C96, C97, C99, C100, C101, C102 | Yageo Group CS0603KRX7R7BB104, | 0.89854 | 12
PESD1CAN,215 | Trans Voltage Suppressor Diode, 200W, 24V V(RWM), Bidirectional, 2 Element, Silicon, TO-236AB | D1 | Nexperia PESD1CAN,215 | 345.3 | 1
SK510BH-LTP | 5A 100V SCHOTTKY SMB | D2, D3 | MCC SK510BH-LTP, | 1.12 | 2
Green | LED GREEN 0603 SMD | D4, D9, D13, D14 | Vishay VLMTG1300-GS08, | 1.45077 | 4
Red | LED RED 0603 SMD | D5 | Vishay VLMS1300-GS08 | 0.23399 | 1
Blue | LED BLUE 0603 SMD | D6 | Vishay VLMB1310-GS08 | 0.35099 | 1
Yellow | LED YELLOW DIFFUSED 0603 SMD | D7 |  |  | 1
White | LED WHITE SMD | D8 |  |  | 1
Green | LED GREEN CLEAR 0603 SMD | D10, D15, D16 | Everlight QTLP601C4TR, | 0.63179 | 3
RS1B-13-F | DIODE GEN PURP 100V 1A SMA | D11, D12, D17 | Diodes Inc. RS1B-13-F, | 1.26357 | 3
0308.500UR | Fuse 0.5A SMD 30V | F1 |  |  | 1
120 Ohms @ 100 MHz | FERRITE BEAD 120 OHM 0805 1LN | FB1, FB2, FB3, FB4, FB5, FB6, FB7, FB8, FB9 | Murata BLM21BB121SN1D, | 1.08807 | 9
3221-14-0300-00 | IDC BOX HEADER, 0.050" (1.27MM), 14 POS LOW PROFILE, SMT, NYLON 6T, G/F | J1 |  |  | 1
206832-0401 | MICRO-FIT Plus Header Assembly Dual Row 4 Position Straight Tin | J2, J7, J8, J9, J10, J13, J14, J15, J26 | Molex 206832-0401, | 11.23174 | 9
7499011222A | 7499011222A Through Hole Lan Ethernet Transformer, 13.95 x 16 x 21.6mm, -40 +85 °C | J3 | Wurth Elektronik 7499011222A | 8.5174 | 1
1939115-1 |  | J4 |  |  | 1
22-28-4020 | Board Connector, 2 Contact(s), 1 Row(s), Male, Straight, 0.1 inch Pitch, Solder Terminal, Locking, Black Insulator, Receptacle | J5, J6 | Molex 22-28-4020, | 0.144 | 2
206832-0602 | Conector macho para PCB Molex serie Micro-Fit+ de 6 vías, 2 filas, paso 3.0mm, Montaje en orificio pasante | J11, J12 | Molex 206832-0602, | 4.98 | 2
206832-0401 | MICRO-FIT Plus Header Assembly Dual Row 4 Position Straight Tin | J16, J17, J18, J19, J20, J21, J22, J23, J24 | Molex 206832-0401, | 11.23174 | 9
216571-2002 | Connector Power Header 2Position 3mm PC Pin Straight Through Hole 2 Terminal 1 Port Tray | J25 | Molex 216571-2002 | 0.467 | 1
DLW43SH510XK2L | Ferrite Chip, 2 Function(s), 50V, 0.23A, 4 Pin(s) | L1 | Murata DLW43SH510XK2L | 239 | 1
7447709220 | WE-PD SMT Power Inductor, size 1210, 22µH, 5.3A, 28mO | L2 | Wurth Elektronik 7447709220 | 2.55054 | 1
744771112 | WE-PD SMT Power Inductor, size 1260, 12µH, 3.91A, 27mO | L3 | Wurth Elektronik 744771112 | 1.05 | 1
BUK9875-100A/CUX | Power Field-Effect Transistor, 7A I(D), 100V, 0.084ohm, 1-Element, N-Channel, Silicon, Metal-oxide Semiconductor FET | Q1, Q2, Q3 | Nexperia BUK9875-100A/CUX, | 3.34495 | 3
10 kOhms | RES 10K OHM 0.1% 1/16W 0603 | R1, R2, R3, R4, R18, R20, R21, R22, R24, R25, R26, R27, R28, R29, R30, R70, R74, R79, R116, R118, R119 | Stackpole Electronics RNCS0603BKE10K0, | 2.70264 | 21
330 Ohms | RES SMD 330 OHM 1% 1/5W 0603 | R5, R6 | TE Connectivity / AMP 2176177-5, | 0.2106 | 2
33 Ohms | RES SMD 33 OHM 0.1% 1/16W 0603 | R7, R8, R9, R14, R15, R16, R17, R23, R31, R32, R33, R34, R35, R36, R37, R38 | TE Connectivity CPF0603B33RE, | 2.78921 | 16
49.9 Ohms | RCC0603 100 49R9 1% ET1 E3 | R10, R11, R12, R13 | Vishay RCC060349R9FKEA, | 0.56159 | 4
6.49 kOhms | RQ 0603 6K49 0.1% 10PPM 1K RL | R19 | TE Connectivity RQ73C1J6K49BTDF | 0.83068 | 1
62 Ohms | RES 10K OHM 0.1% 1/16W 0603 | R39, R43 | Stackpole Electronics RNCS0603BKE10K0, | 0.30419 | 2
100 Ohms | RES 100 OHM 1% 1/10W 0603 | R40, R41, R42 | Vishay CRCW0603100RFKEAC, | 0.28079 | 3
330 kOhms | RES 332K OHM 1% 1/10W 0603 | R44 | KOA Speer RK73H1JTTD3323F | 0.0936 | 1
220 kOhms | RES SMD 909K OHM 1% 1/10W 0603 | R45 | Vishay CRCW0603909KFKEA | 0.0936 | 1
10 kOhms | RES SMD 10K OHM 1% 1/10W 0603 | R46 | Yageo Group RT0603FRE0710KL | 0.0936 | 1
100 kOhms | RES 100K OHM 0.1% 1/16W 0603 | R47, R48, R52 | Stackpole Electronics RNCS0603BKE100K, | 0.45629 | 3
56 kOhms | RES SMD 316K OHM 1% 1/10W 0603 | R49 | Vishay CRCW0603316KFKEA | 0.0936 | 1
68 kOhms | RES SMD 249K OHM 0.1% 1/10W 0603 | R50 |  |  | 1
39 kOhms | RES SMD 41.2K OHM 1% 1/10W 0603 | R51 | Bourns CR0603-FX-4122ELF | 0.0936 | 1
2.2 kOhms | RES SMD 41.2K OHM 1% 1/10W 0603 | R53 | Bourns CR0603-FX-4122ELF | 0.0936 | 1
1 kOhms | RES 10K OHM 0.1% 1/16W 0603 | R54, R55, R56, R57, R58, R59, R60, R61, R62 | Stackpole Electronics RNCS0603BKE10K0, | 1.28697 | 9
330 Ohms | RES 330 OHM 1% 1/10W 0603 | R63, R65, R123 | TE Connectivity CRGCQ0603F330R, | 0.28079 | 3
10kOhms | RES 330 OHM 1% 1/10W 0603 | R64, R66, R124 | TE Connectivity CRGCQ0603F330R, | 0.28079 | 3
10 kOhms | RES SMD 10K OHM 0.1% 1/10W 0603 | R67, R69, R72, R78 | Vishay MCT06030D1002BP500, | 0.56159 | 4
1 kOhms | RES SMD 1K OHM 1% 1/10W 0603 | R68, R73, R86, R89 | Yageo Group RT0603FRE071KL, | 0.117 | 4
47kOhms | RES SMD 100K OHM 1% 1/10W 0603 | R71, R80 | Yageo Group RT0603FRE07100KL, | 0.117 | 2
10kOhms | RES SMD 316K OHM 1% 1/10W 0603 | R75, R84 | Yageo Group AC0603FR-07316KL, | 0.1872 | 2
2.2 kOhms | RES 332K OHM 1% 1/10W 0603 | R76 | KOA Speer RK73H1JTTD3323F | 0.0936 | 1
680 kOhms | RES SMD 909K OHM 1% 1/10W 0603 | R77 | Vishay CRCW0603909KFKEA | 0.0936 | 1
2.7 kOhms | RES SMD 10K OHM 1% 1/10W 0603 | R81 | Yageo Group RT0603FRE0710KL | 0.0936 | 1
180 kOhms | RES SMD 249K OHM 0.1% 1/10W 0603 | R82 |  |  | 1
270 kOhms | RES SMD 316K OHM 1% 1/10W 0603 | R83 | Vishay CRCW0603316KFKEA | 0.0936 | 1
12kOhms | RES SMD 4.7K OHM 0.1% 1/10W 0603 | R85, R88 | Yageo Group RT0603BRD074K7L, | 0.1872 | 2
33kOhms | RES SMD 9.1K OHM 0.1% 1/10W 0603 | R87, R90 | Yageo Group RT0603BRD079K1L, | 0.1872 | 2
100 kOhms | RES 100K OHM 1% 1/10W 0603 | R91 | Vishay CRCW0603100KFKEAC | 0.0936 | 1
0 Ohm | RES SMD 0 OHM JUMPER 1/10W 0603 | R92 | TE Connectivity CRG0603ZR |  | 1
5.1kOhms | RES SMD 10K OHM 1% 1/10W 0603 | R93 | Yageo Group RT0603FRE0710KL | 0.0936 | 1
10kOhms | RES SMD 4.7K OHM 0.1% 1/10W 0603 | R94 | Yageo Group RT0603BRD074K7L | 0.0936 | 1
39 kOhms | RES SMD 10K OHM 1% 1/10W 0603 | R95 | Yageo Group RT0603FRE0710KL | 0.0936 | 1
1kOhms |  | R96 | Yageo Group RC0603JR-101KL | 0.0936 | 1
68 kOhms | RES 6.8K OHM 1% 1/10W 0603 | R97 | Stackpole Electronics RMCF0603FT6K80 | 0.0936 | 1
39 kOhms | RES SMD 39K OHM 0.1% 1/10W 0603 | R98, R99, R100, R101, R102, R103, R105, R106, R108, R109, R110, R111, R112, R113, R114, R115 |  |  | 16
0 Ohms | RES 0 OHM JUMPER 0603 | R104, R107 | KOA Speer TLRZ1JTTD, | 0.77218 | 2
100 kOhms | RES SMD 100K OHM 1% 1/10W 0603 | R117 | Yageo Group RT0603FRE07100KL | 0.0936 | 1
1.5 kOhms | RES 10K OHM 0.1% 1/16W 0603 | R120, R121 | Stackpole Electronics RNCS0603BKE10K0, | 0.30419 | 2
270 kOhms | RES SMD 316K OHM 1% 1/10W 0603 | R122 | Yageo Group AC0603FR-07316KL | 0.0936 | 1
10 Ohms | RES SMD 10K OHM 1% 1/10W 0603 | R125, R126 | Yageo Group RT0603FRE0710KL, | 0.117 | 2
82306050029 |  | RV1, RV2, RV3, RV4, RV5, RV6, RV7, RV8, RV9, RV10, RV11, RV12 | Wurth Elektronik 82306050029, | 8.70459 | 12
M3 Screw |  | SC1, SC2, SC3, SC4 |  |  | 4
STM32H723ZG | Arm® Cortex®-M7 32-bit 550 MHz MCU, up to 1 MB Flash, 564 KB RAM, Ethernet, USB, 3x FD-CAN, Graphics, 2x 16-bit ADCs | U1 |  |  | 1
KSZ8041TLI | IC ETHERNET PHY IND 48-TQFP | U2 | Microchip KSZ8041TLI | 3.18584 | 1
TJA1051T/3,118 | High Speed CAN Transceiver | U3 | NXP Semiconductors TJA1051T/3,118 | 1803.25 | 1
LM5013-Q1 | 100-V Input, 3.5-A Non-Synchronous Buck DC/DC Converter with Ultra-low IQ | U4 |  |  | 1
LM5013-Q1 |  | U5 |  |  | 1
LT1963AEST-3.3#TRPBF | Fixed Positive LDO Regulator, 3.3V, 0.55V Dropout, BIPolar, PDSO3 | U6 | Analog Devices LT1963AEST-3.3#TRPBF | 3.668 | 1
ULN2002A | ULN200x, ULQ200x High-Voltage, High-Current Darlington Transistor Arrays | U7 |  |  | 1
MCP6022-E/SN | Operational Amplifier, 2 Func, 2500uV Offset-Max, CMOS, PDSO8 | U8, U12, U14 | Microchip MCP6022-E/SN, | 5.33507 | 3
SN74HC32DR | 4-ch 2-input 2-V to 6-V 5.2 mA drive strength OR gate 14-SOIC -40 to 85 | U15, U18 | Texas Instruments SN74HC32DR, | 0.1434 | 2
SN74ALVC08IPWRQ1 | AND Gate, ALVC/VCX/A Series, 4-Func, 2-Input, CMOS, PDSO14 | U16, U17 | Texas Instruments SN74ALVC08IPWRQ1, | 1.12 | 2
LM339PWR | Comparator, 4 Func, 5000uV Offset-Max, 300ns Response Time, BIPolar, PDSO14 | U19 | Texas Instruments LM339PWR | 218.8 | 1
25.000MHZ | 25.000 MHz Ultra miniature ceramic glass sealed SMD crystal. | X1 |  |  | 1
32.768KHZ | 32.768kHz Crystal | X2 |  |  | 1
50 MHz | XTAL OSC XO 50.0000MHZ CMOS SMD | Y1 |  |  | 1

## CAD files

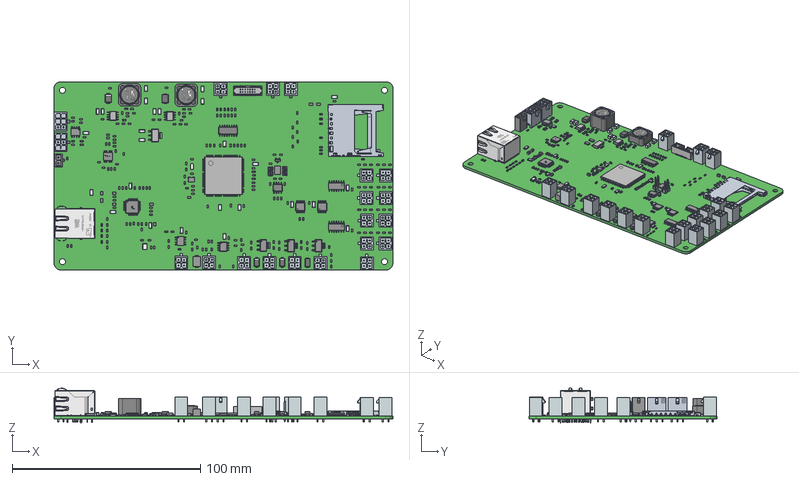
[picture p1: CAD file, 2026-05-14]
docs/STEP_[No Variations] for PCB.PcbDoc.step
180.0 x 100.0 x 18.4 mm
0603 resistor x 124
PinsArrayL x 3
FilletPinR x 3
SMA x 3
LED 0603 Base GREEN x 7
LED 0603 Lens GREEN x 7
Leader x 184
Abracon ASE
Pins x 2
Texas Instruments CD40106BPWR 1
Texas Instruments CD40106BPWR 2 x 16
Texas Instruments CD40106BPWR 2_MIR x 7
Texas Instruments
BODY_M14A_20 x 2
LEAD_M14A_46 x 28
BODY_MTC14 x 2
LEAD_MTC14 x 28
PinsArrayLR x 3
Lead x 3
Tab
Leg x 2
Microchip logo
Microchip Logo 1
contacs x 12
ceramic substrate x 12
Over Coat x 12
Extruded x 4
Substrate
Terminals
Coating
Logo
Leadframe x 4
Core x 2
ShieldRing x 2
Glue x 2
coil
terminals
top
logo
801-2195-14-K
2195SM-PIN x 14
FER 0805 x 9
LED 0603 Lens WHITE
LED 0603 Lens YELLOW
LED 0603 Base YELLOW
LED 0603 Lens BLUE
LED 0603 Base BLUE
LED 0603 Base RED
LED 0603 Lens RED
SMB x 2
SOT23
0603 cap x 72
CAP 1206-0.8mm x 18
CAP 1206-1.8mm x 8
Murata - GQM187 x 2

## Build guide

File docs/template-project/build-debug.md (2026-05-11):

# Build and Debug

## 1. Main CMake Presets

- `simulator`
- `simulator-asan`
- `nucleo-*`
- `board-*`

## 2. Build for Simulator

```sh
./hyper build main --preset simulator
```

With sanitizers:

```sh
./hyper build main --preset simulator-asan
```

## 3. Build for MCU

VCU board build:

```sh
./hyper build main --preset board-debug-eth-ksz8041 --board-name VCU
```

The build output is copied to:

- `out/build/latest.elf`

If the selected `BOARD_NAME` enables packet code generation, the build also regenerates:

- `Core/Inc/Communications/Packets/DataPackets.hpp`
- `Core/Inc/Communications/Packets/OrderPackets.hpp`

These headers are generated artifacts, not hand-maintained source files. They are gitignored and should not be edited or committed.

## 4. Debug from VSCode

Launch configurations available in `.vscode/launch.json`:

- `MCU | OpenOCD | Build + Debug (RTT)`
- `MCU | OpenOCD | Debug (No Build, RTT)`
- `MCU | OpenOCD | Attach (External Server, RTT)`
- `MCU | ST-LINK | Build + Debug`
- `MCU | ST-LINK | Debug (No Build)`
- `MCU | ST-LINK | Attach (External GDB Server)`
- `SIM | ST-LIB Tests | Debug`

Useful tasks in `.vscode/tasks.json`:

- `MCU | OpenOCD | Start Server`
- `MCU | OpenOCD | RTT Console`
- `MCU | ST-LINK | Start GDB Server`

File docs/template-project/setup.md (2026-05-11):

# Template Project Setup

## 1. Prerequisites

- VSCode (recommended)
- CMake + Ninja
- Python 3

For MCU build/flash/debug:

- `STM32CubeCLT`
- `openocd` or `ST-LINK_gdbserver`
- `arm-none-eabi-gdb`
- `tio` (recommended for `./hyper uart`; `cu` remains the fallback when available)

## 2. Quick Initialization

From the repository root:

```sh
./hyper init
```

This command:

- creates `virtual/`
- installs Python dependencies from `requirements.txt`
- initializes template and `deps/ST-LIB` submodules

On Windows:

```bat
python hyper init
```

## 3. `BOARD_NAME` Configuration (codegen)

Code generation uses `BOARD_NAME` (CMake cache variable), and the value must exist in:

- `Core/Inc/Code_generation/JSON_ADE/boards.json`

Example:

```sh
./hyper build main --preset board-debug --board-name TEST
```

If not set, the default value is `TEST`.

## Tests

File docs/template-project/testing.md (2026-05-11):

# Testing and Quality

## 1. Local Simulator Tests

```sh
./hyper stlib build --preset simulator --run-tests
```

Run only ADC tests:

```sh
./hyper stlib build --preset simulator
ctest --preset simulator-adc
```

## 2. Tests with Sanitizers

```sh
./hyper stlib build --preset simulator-asan
ctest --preset simulator-all-asan
```

## 3. Formatting

This repository uses `pre-commit` and `clang-format`.

Install hooks:

```sh
pip install pre-commit
pre-commit install --install-hooks --hook-type pre-commit --hook-type pre-push
```

Run manually:

```sh
pre-commit run --all-files
```

## 4. GitHub Actions CI

- `Compile Checks`: builds MCU matrix (no simulator tests)
- `Run Simulator Tests`: runs tests using `simulator` preset
- `Format Checks`: validates formatting with `pre-commit`

## 5. Generated Packet Headers

`Core/Inc/Communications/Packets/DataPackets.hpp` and `Core/Inc/Communications/Packets/OrderPackets.hpp` are generated from the active `JSON_ADE` schema during build. They are intentionally gitignored and should not be committed.

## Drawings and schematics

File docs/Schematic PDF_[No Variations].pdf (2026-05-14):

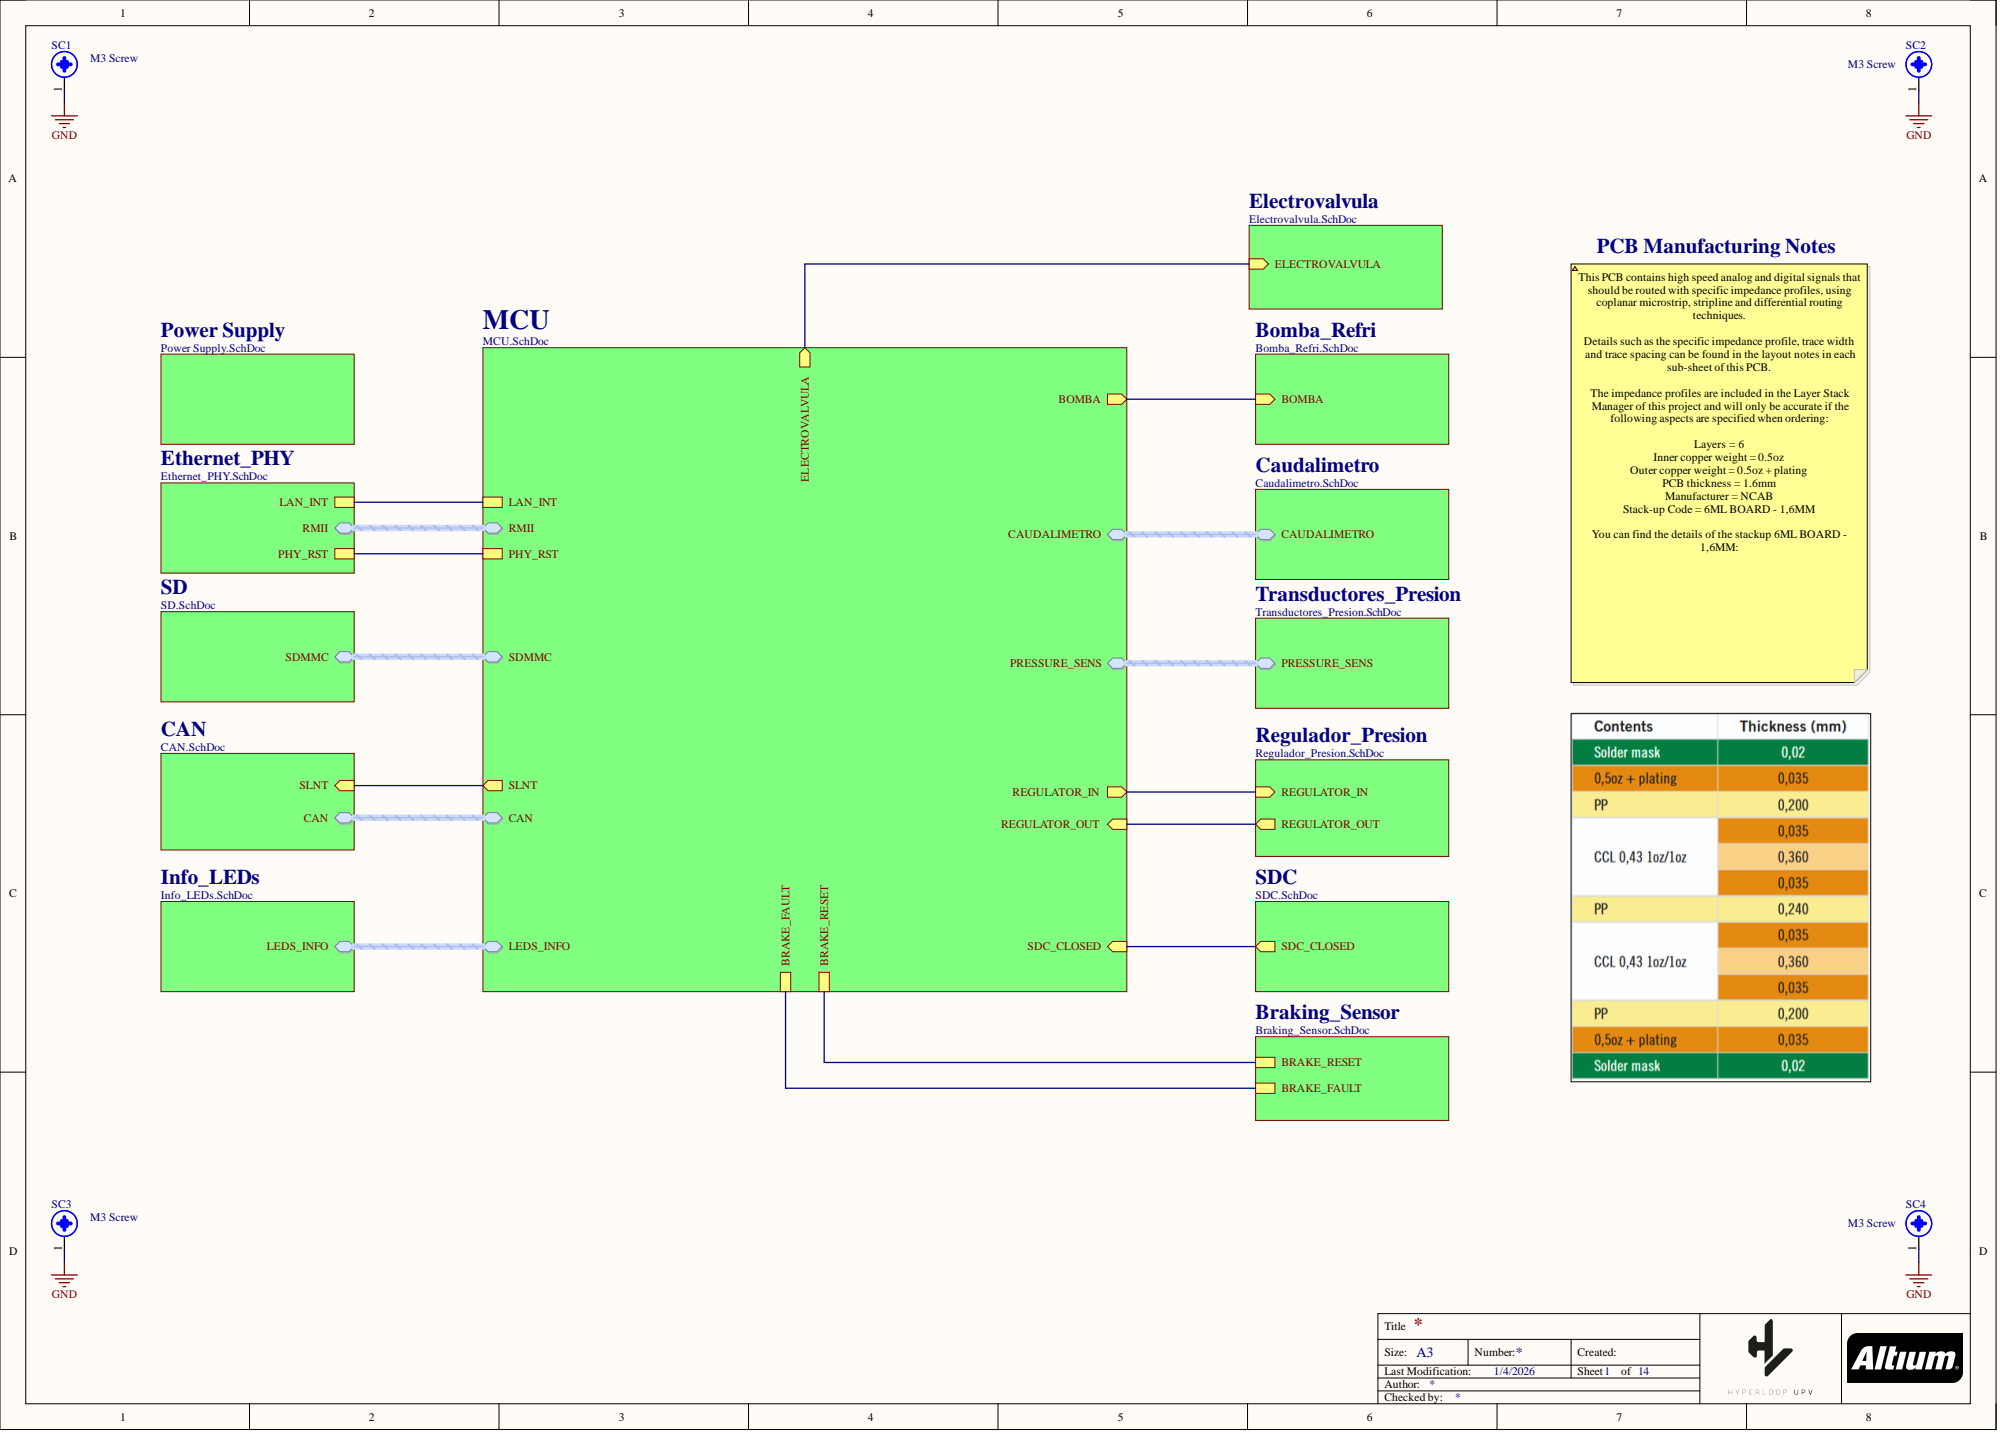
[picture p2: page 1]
i Bomba_Refri.SchDoc; r Braking_Sensor.SchDoc; s Info_LEDs.SchDoc; M3 Screw; s PCB co; peed anal; be ro lanar micro; ial ro; uch as; g can; n each; s PCB.; les are; Layer Stack; project an; be accurate; s are; Layers = 6; ner co; ter co; s = urer =; ARD -; u can fi

PCB Manufacturing Notes

ro Caudalimetro.SchDoc ELECTROVALVULA

Power Supply Power Supply.SchDoc

Size : | N umb er | Created
Las t Mo d ificat o n / | | Shee f

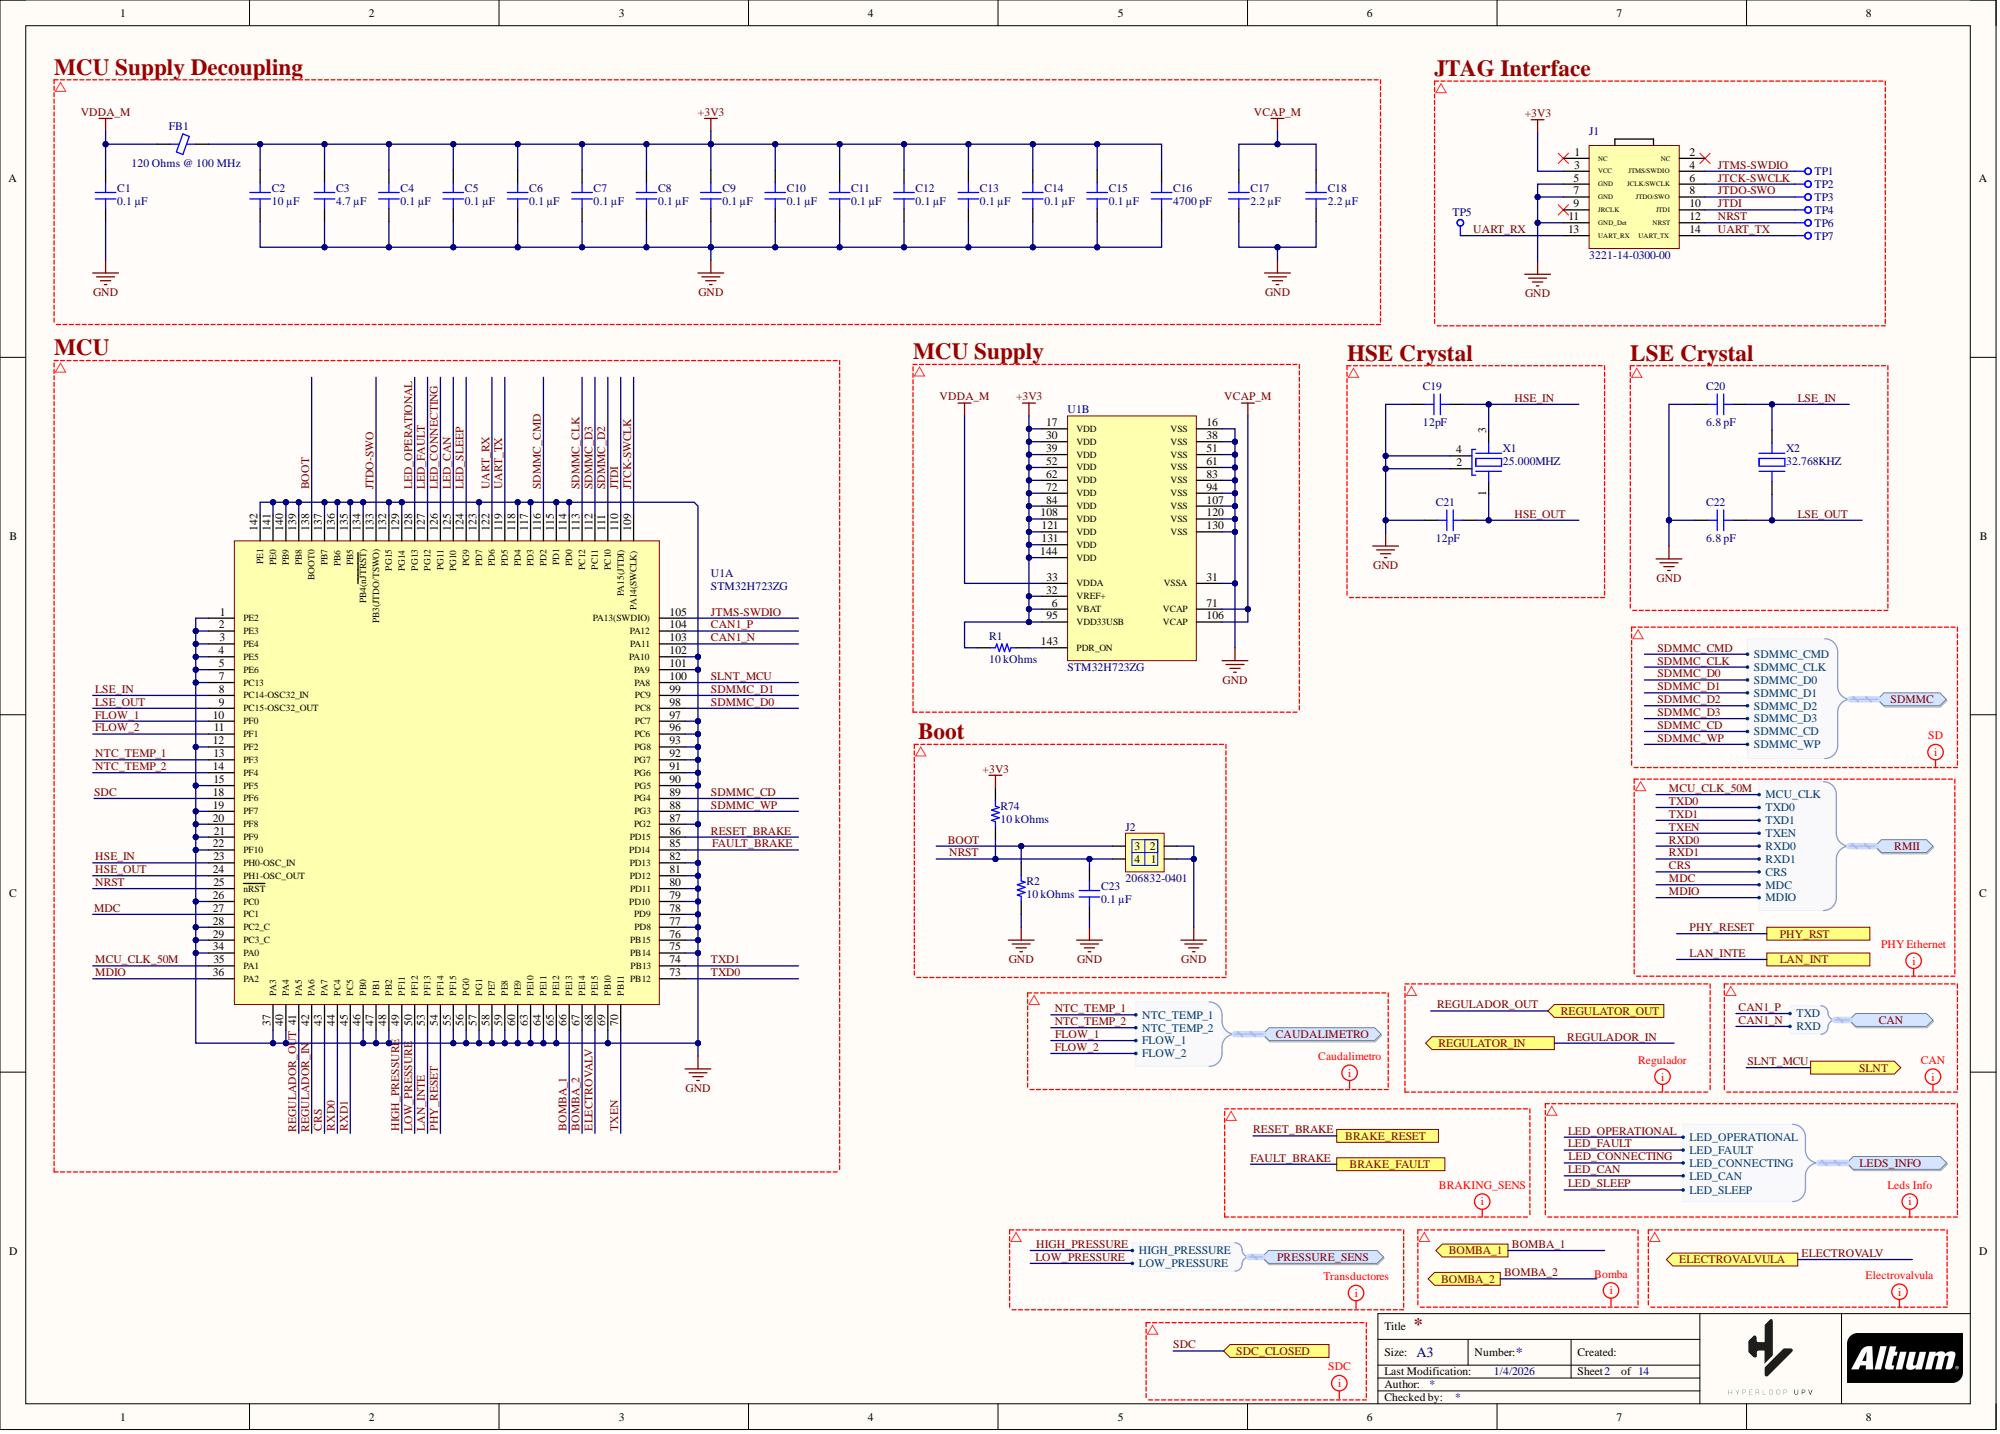
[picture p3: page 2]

Title

Size: A3 | Number: | Created:
Last Modification: | | Sheet of

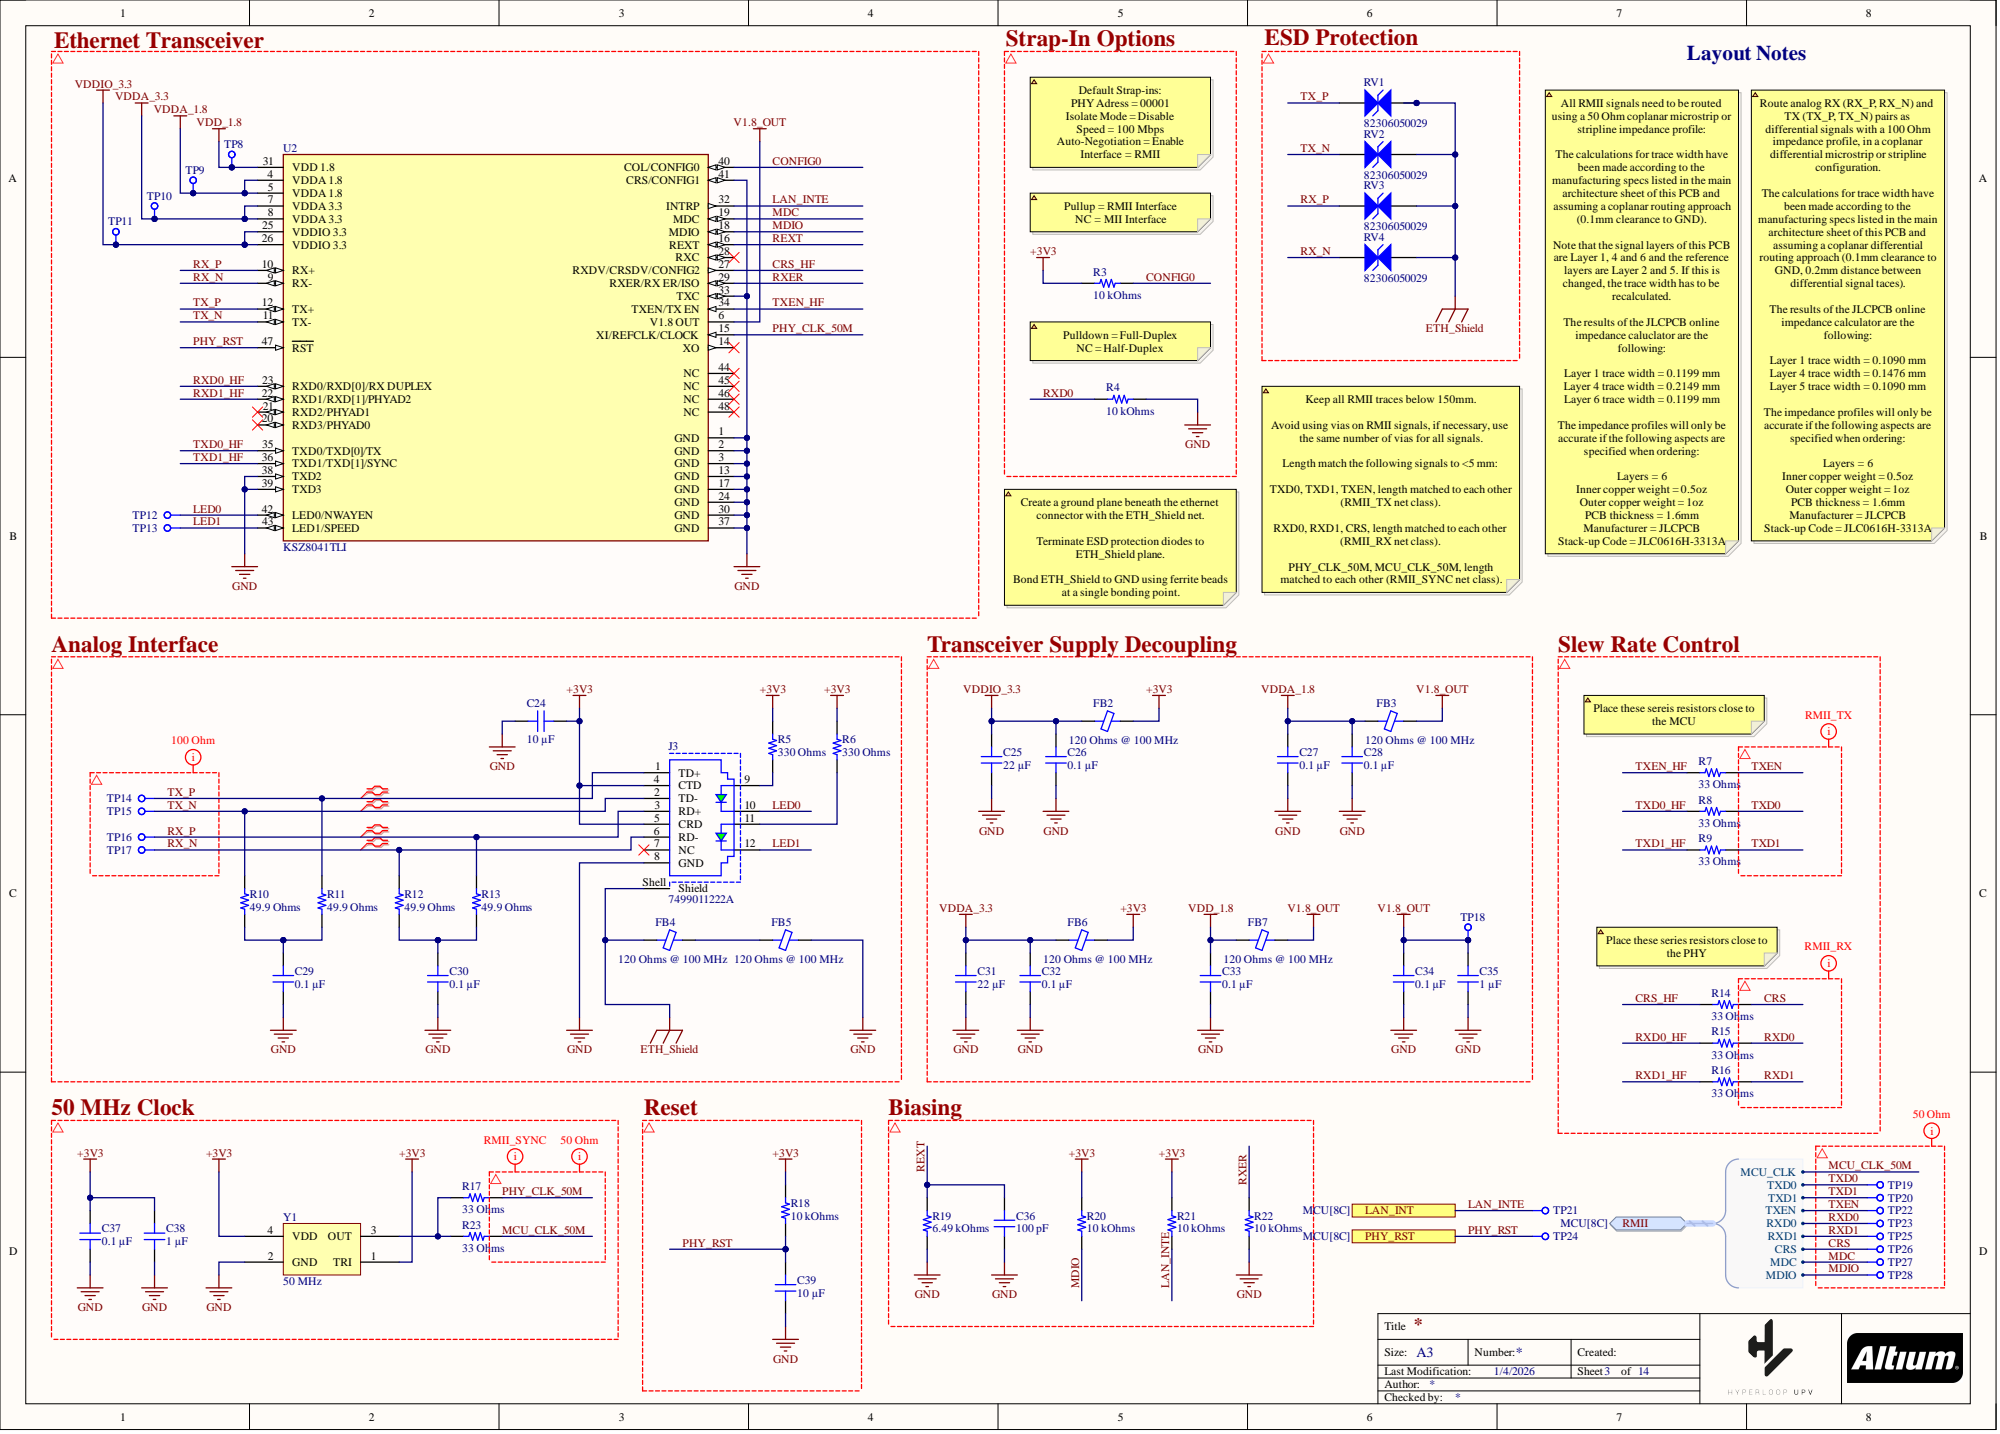
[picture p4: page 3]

TP11 | VDDA_1.8

All RMII signals need to be routed
using a 50 Ohm coplanar microstrip or
stripline impedance profile:

Route analog RX (RX_P, RX_N) and
TX (TX_P, TX_N) pairs as
differential signals with a 100 Ohm
impedance profile, in a coplanar
differential microstrip or stripline

TP10 | VDD_1.8

The calculations for trace width have
been made according to the
manufacturing specslisted in the main
architecture sheet of this PCB and
assuming a coplanar routing approach
(0.1mm clearance to GND).

assuming a coplanar differential
routing approach (0.1mm clearance to
GND, 0.2mm distance between
differentialsignal taces).

VDDA 3.3 7

Note that the signal layers of this PCB
are Layer 1, 4 and 6 and the reference
layers are Layer 2 and 5. If this is
changed, the trace width has to be

The results of the JLCPCB online
impedance calculator are the

impedance caluclator are the

Layer 1 trace width = 0.1090 mm
Layer 4 trace width = 0.1476 mm
Layer 5 trace width = 0.1090 mm

Layer 1 trace width = 0.1199 mm
Layer 4 trace width = 0.2149 mm
Layer 6 trace width = 0.1199 mm

Keep all RMII traces below 150mm.

The impedance profiles will only be
accurate if the following aspects are
specified when ordering:

Avoid using vias on RMII signals, if necessary, use
the same number of vias for all signals.

Length match the following signals to <5 mm:

TXD0, TXD1, TXEN, length matched to each other

Create a ground plane beneath the ethernet
connector with the ETH_Shield net.

RXD0, RXD1, CRS, length matched to each other

Terminate ESD protection diodes to

PHY_CLK_50M, MCU_CLK_50M, length
matched to each other (RMII_SYNC net class).

Bond ETH_Shield to GND using ferrite beads

at a single bonding point.

Place these sereis resistors close to

GND 8

Place these series resistors close to

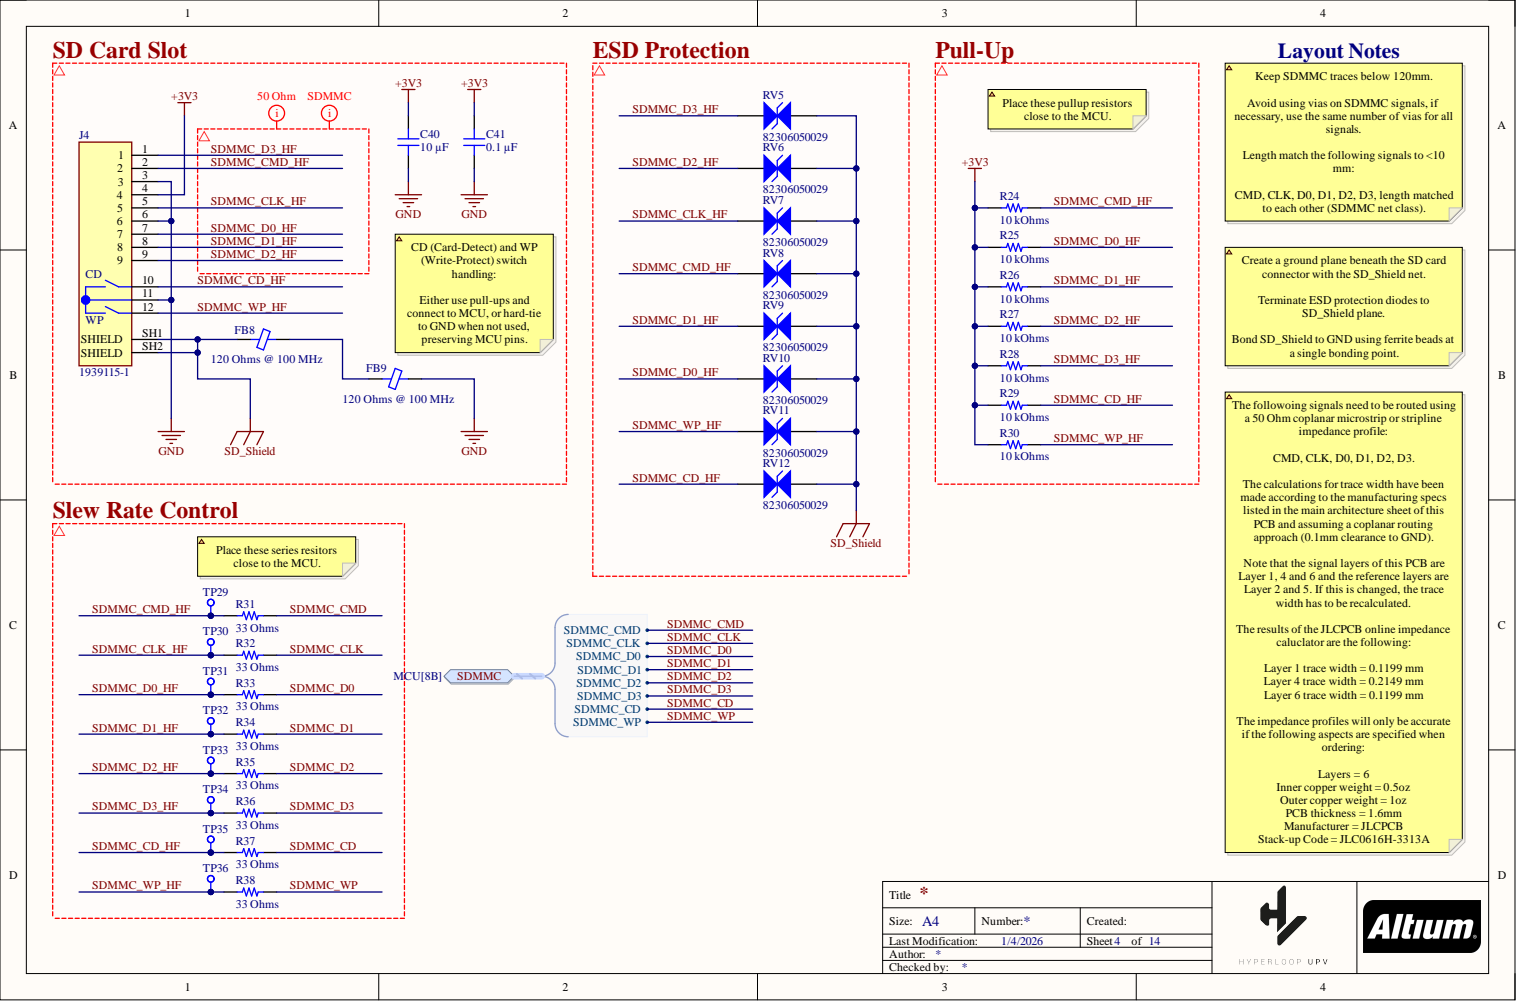
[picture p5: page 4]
SD Card Slot; ESD Protection; Pull-Up 1; 1 SDMMC_CMD_HF; hms @; FB9 120 Ohms @; out Notes; D SDMMC_CMD; series res he MCU; Create a; g ferri; p res he MCU; o MCU,; g MCU; Keep SDMMC; n SDMMC; h match; CMD, CL; h matched; o each; her (SDMMC; net clas; lanar micro; he calcu; s for; made accord; he man; he mai; n arch; PCB an; lanar ro proach (0.1mm clearance; s PCB are; he reference; layers are; s chan be recalcu; he res; or are; be accurate; s are; Layers = 6; ner co; ter co; s = urer =

ias for al

CD (Card-Detect) an
(Wri

he SD card

Slew Rate Control

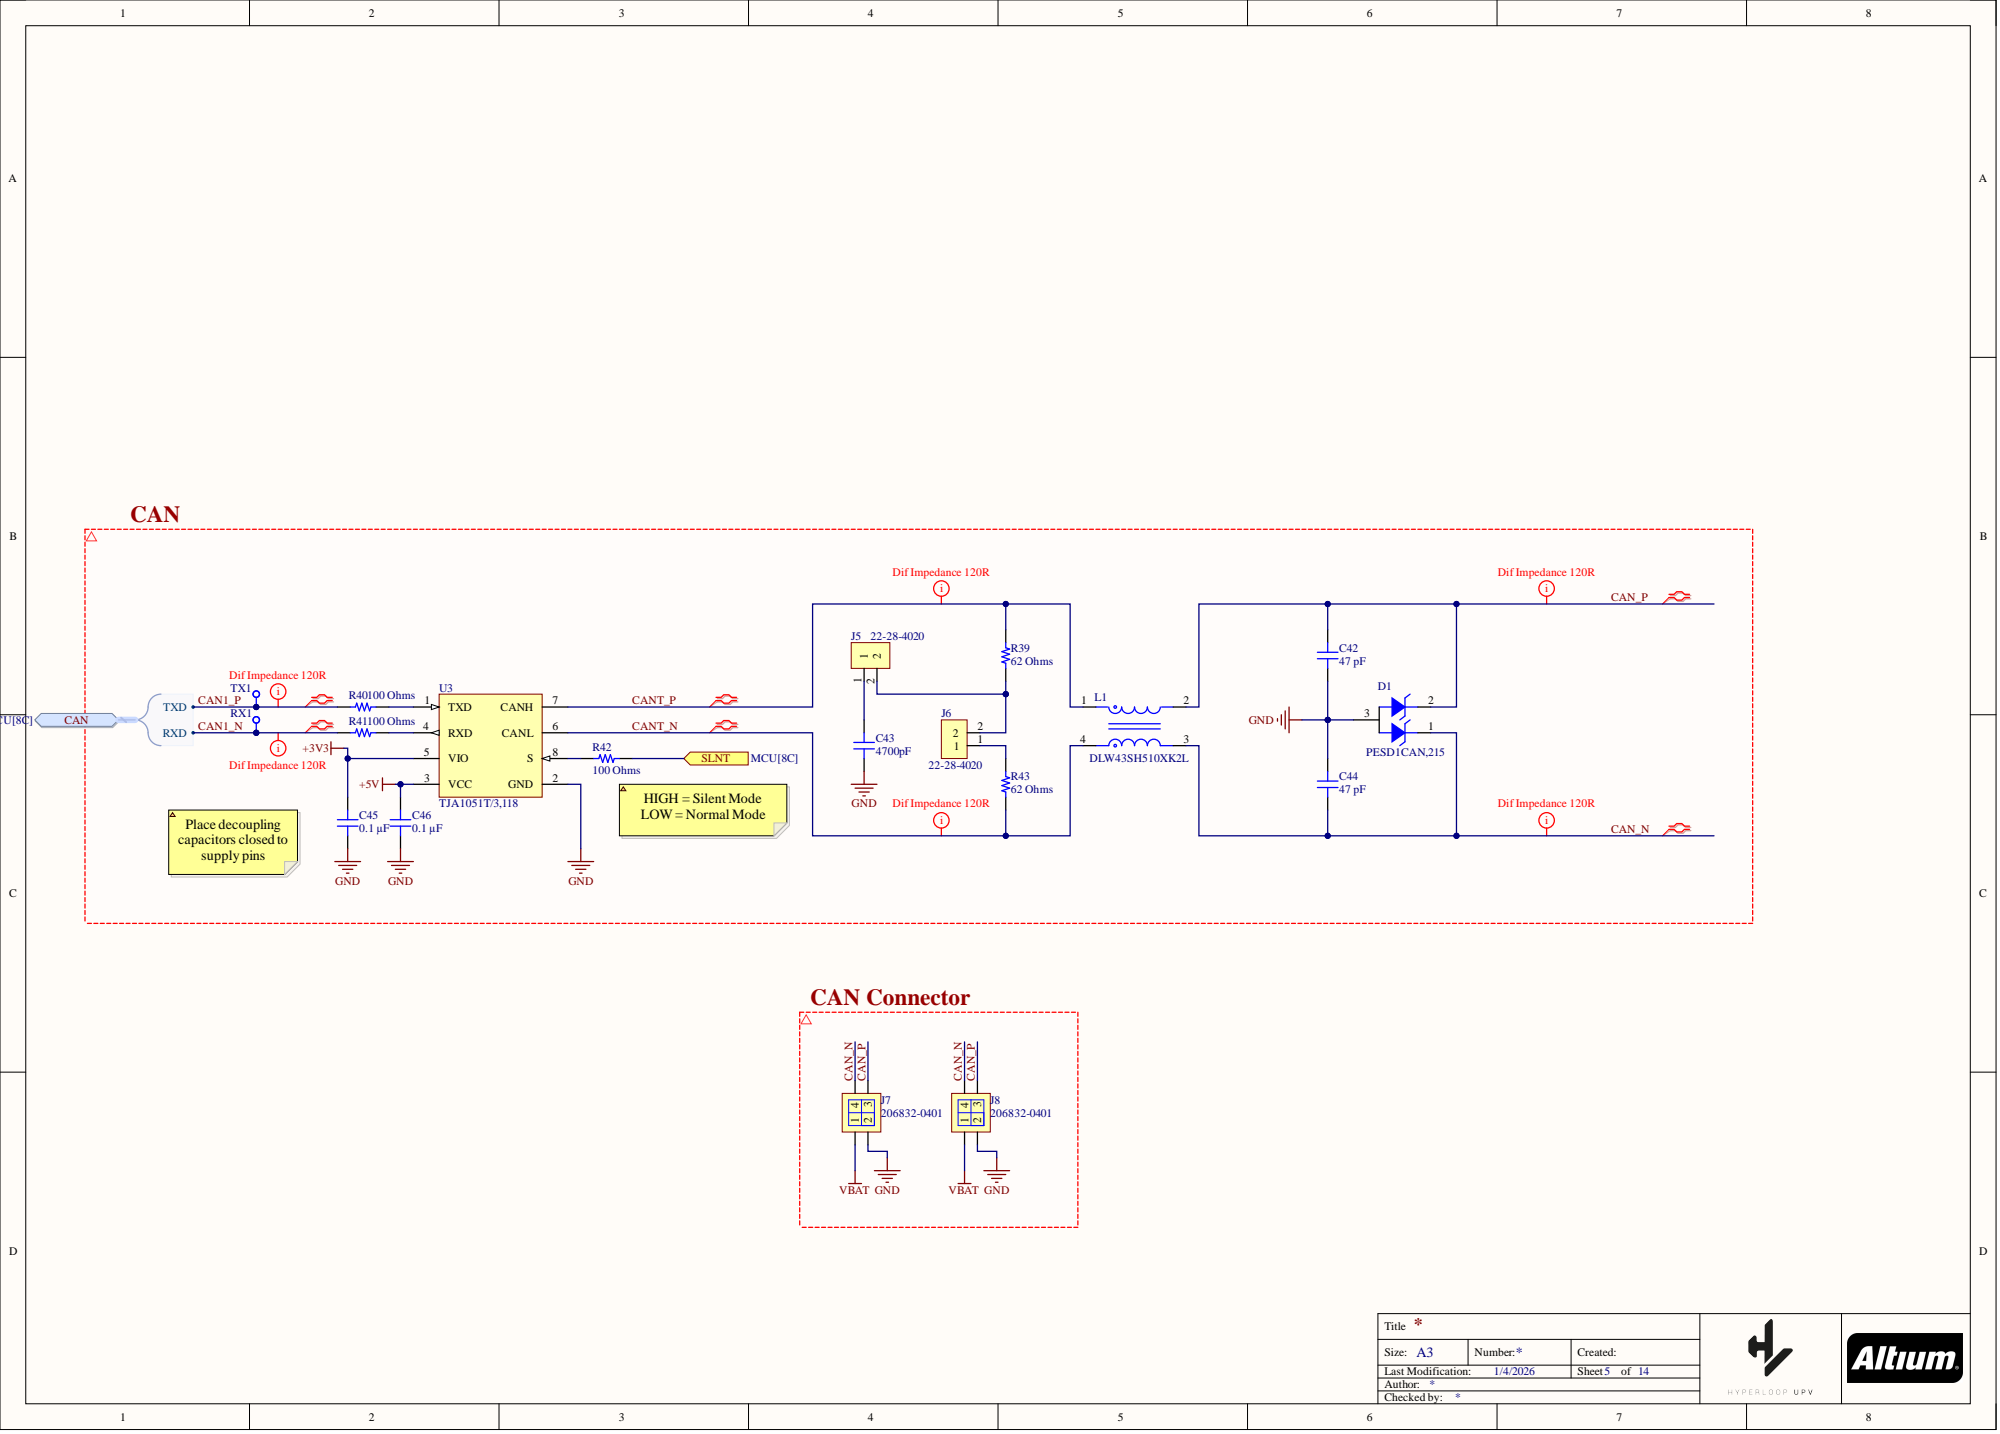
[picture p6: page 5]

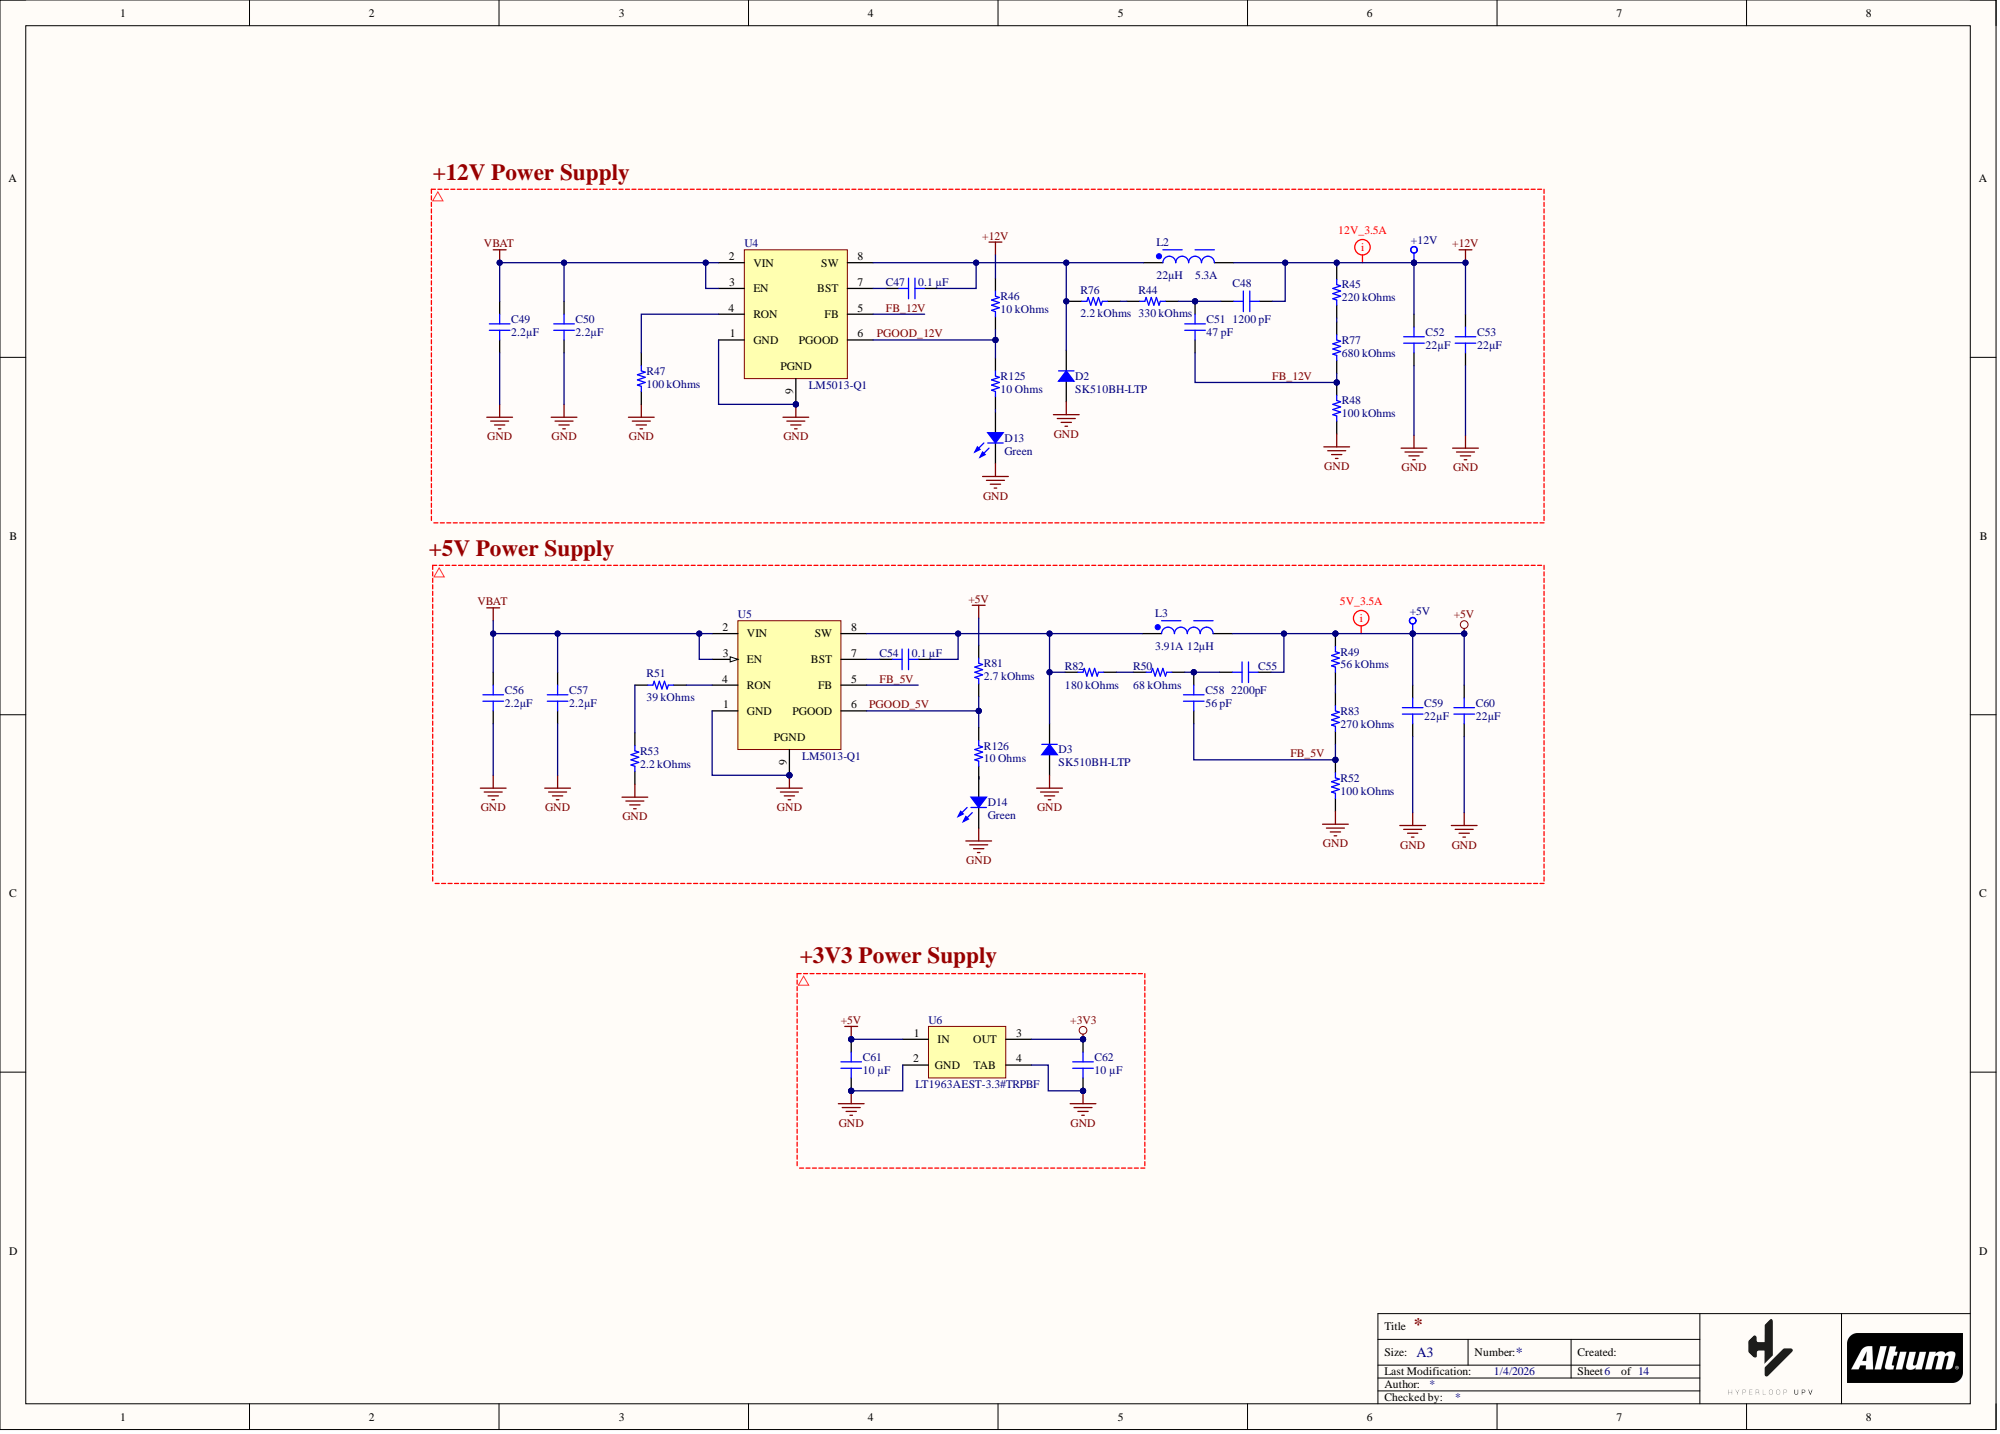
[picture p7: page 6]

PGND

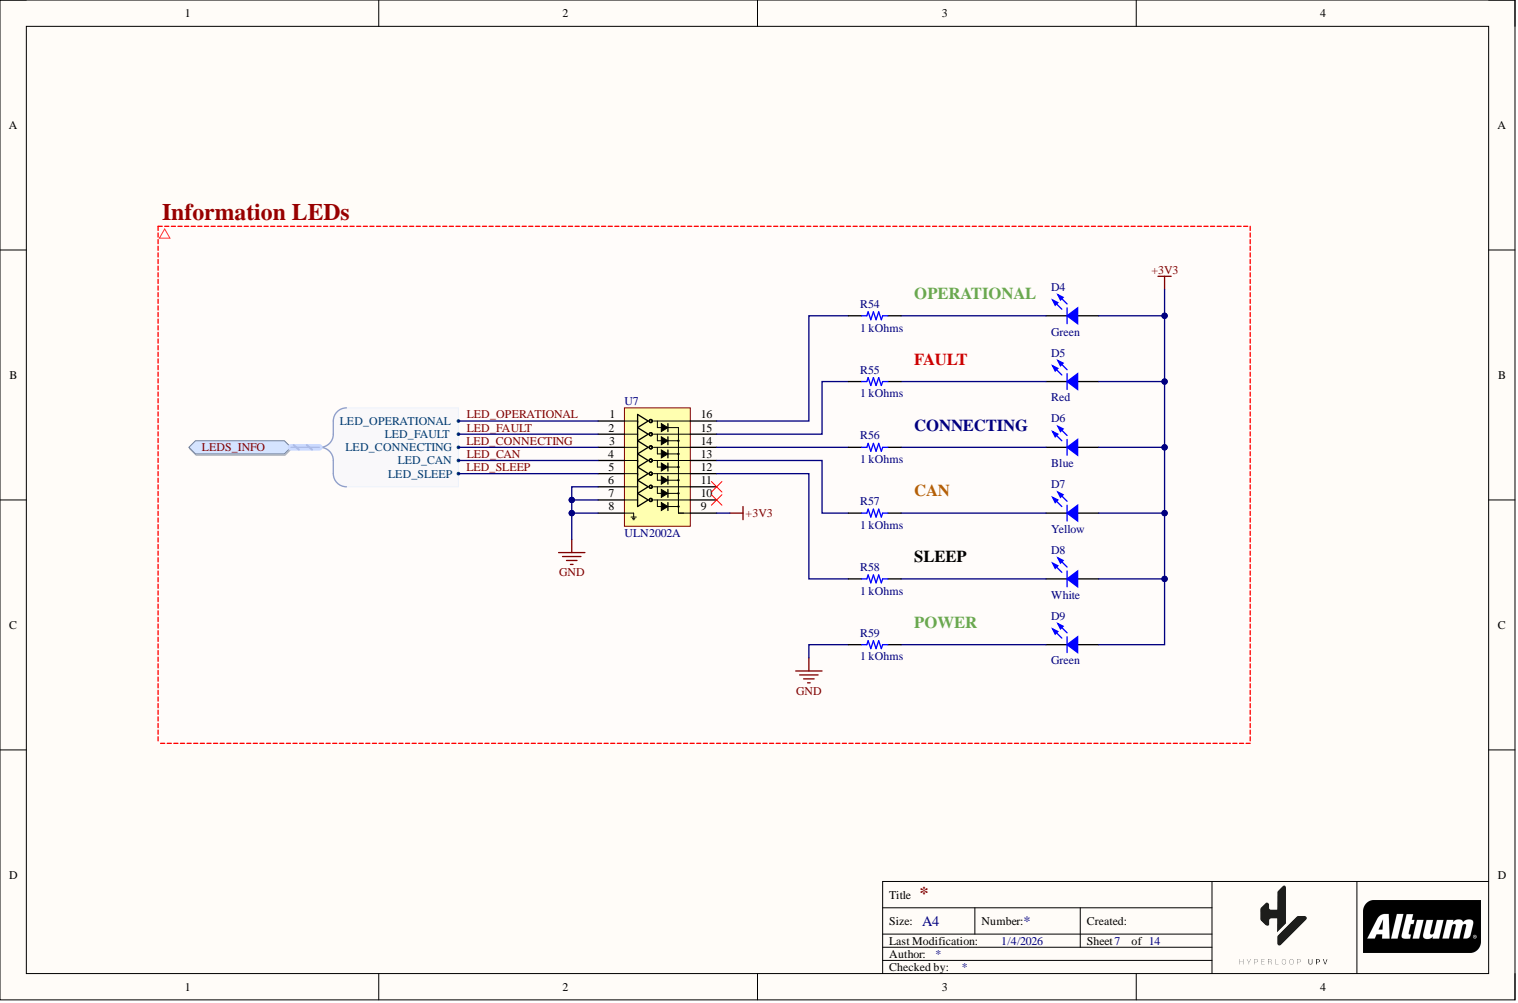
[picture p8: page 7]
Green D5; Red D6; Information LEDs

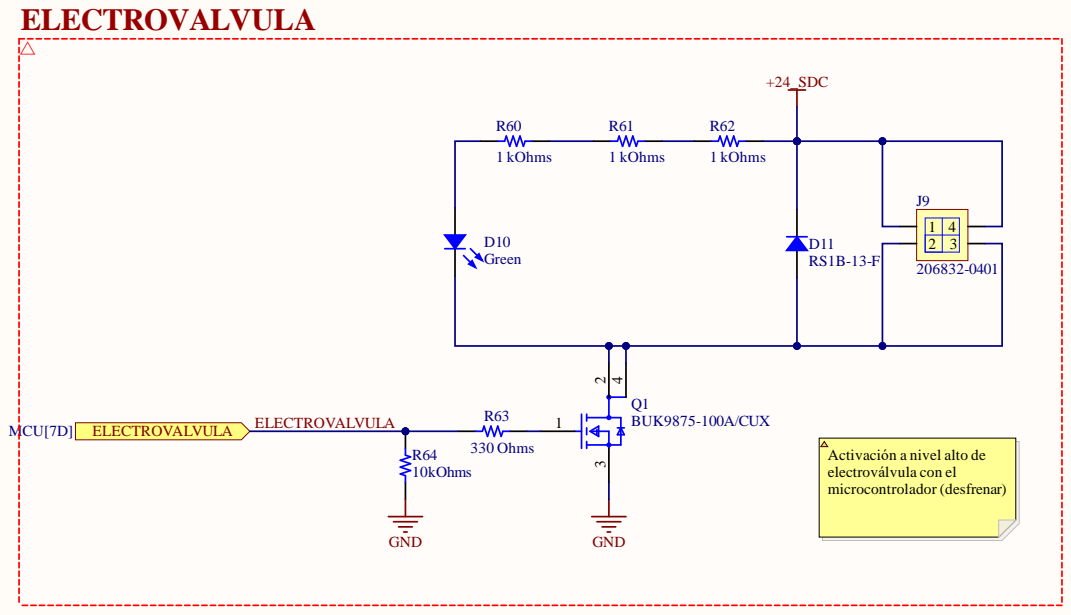
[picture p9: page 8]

+24_SDC

Activación a nivel alto de
electroválvula con el
microcontrolador (desfrenar)

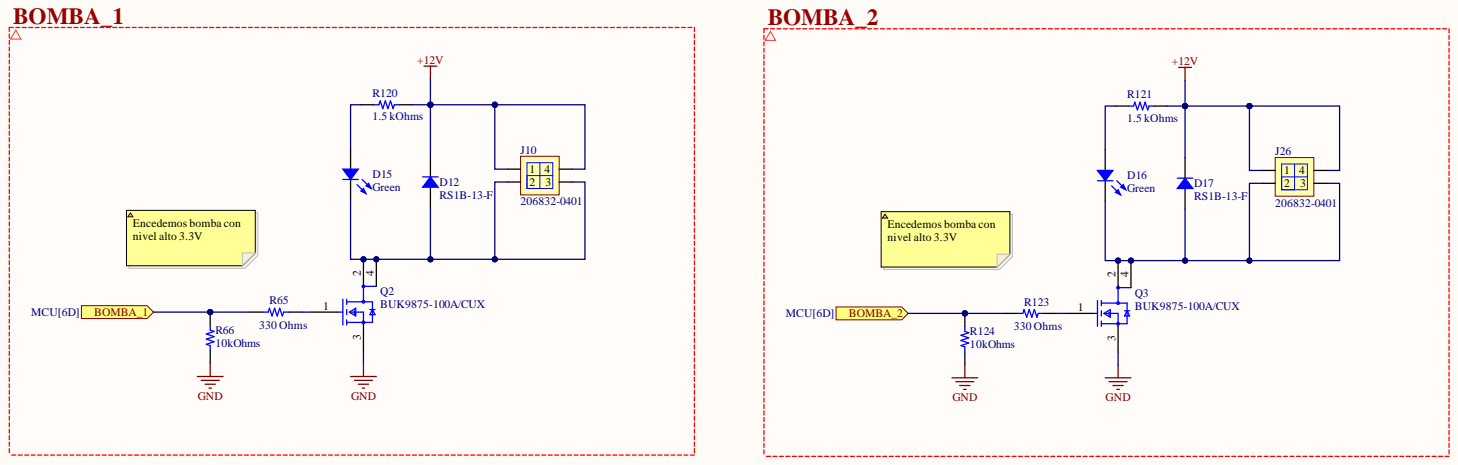
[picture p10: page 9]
omba co; vel al

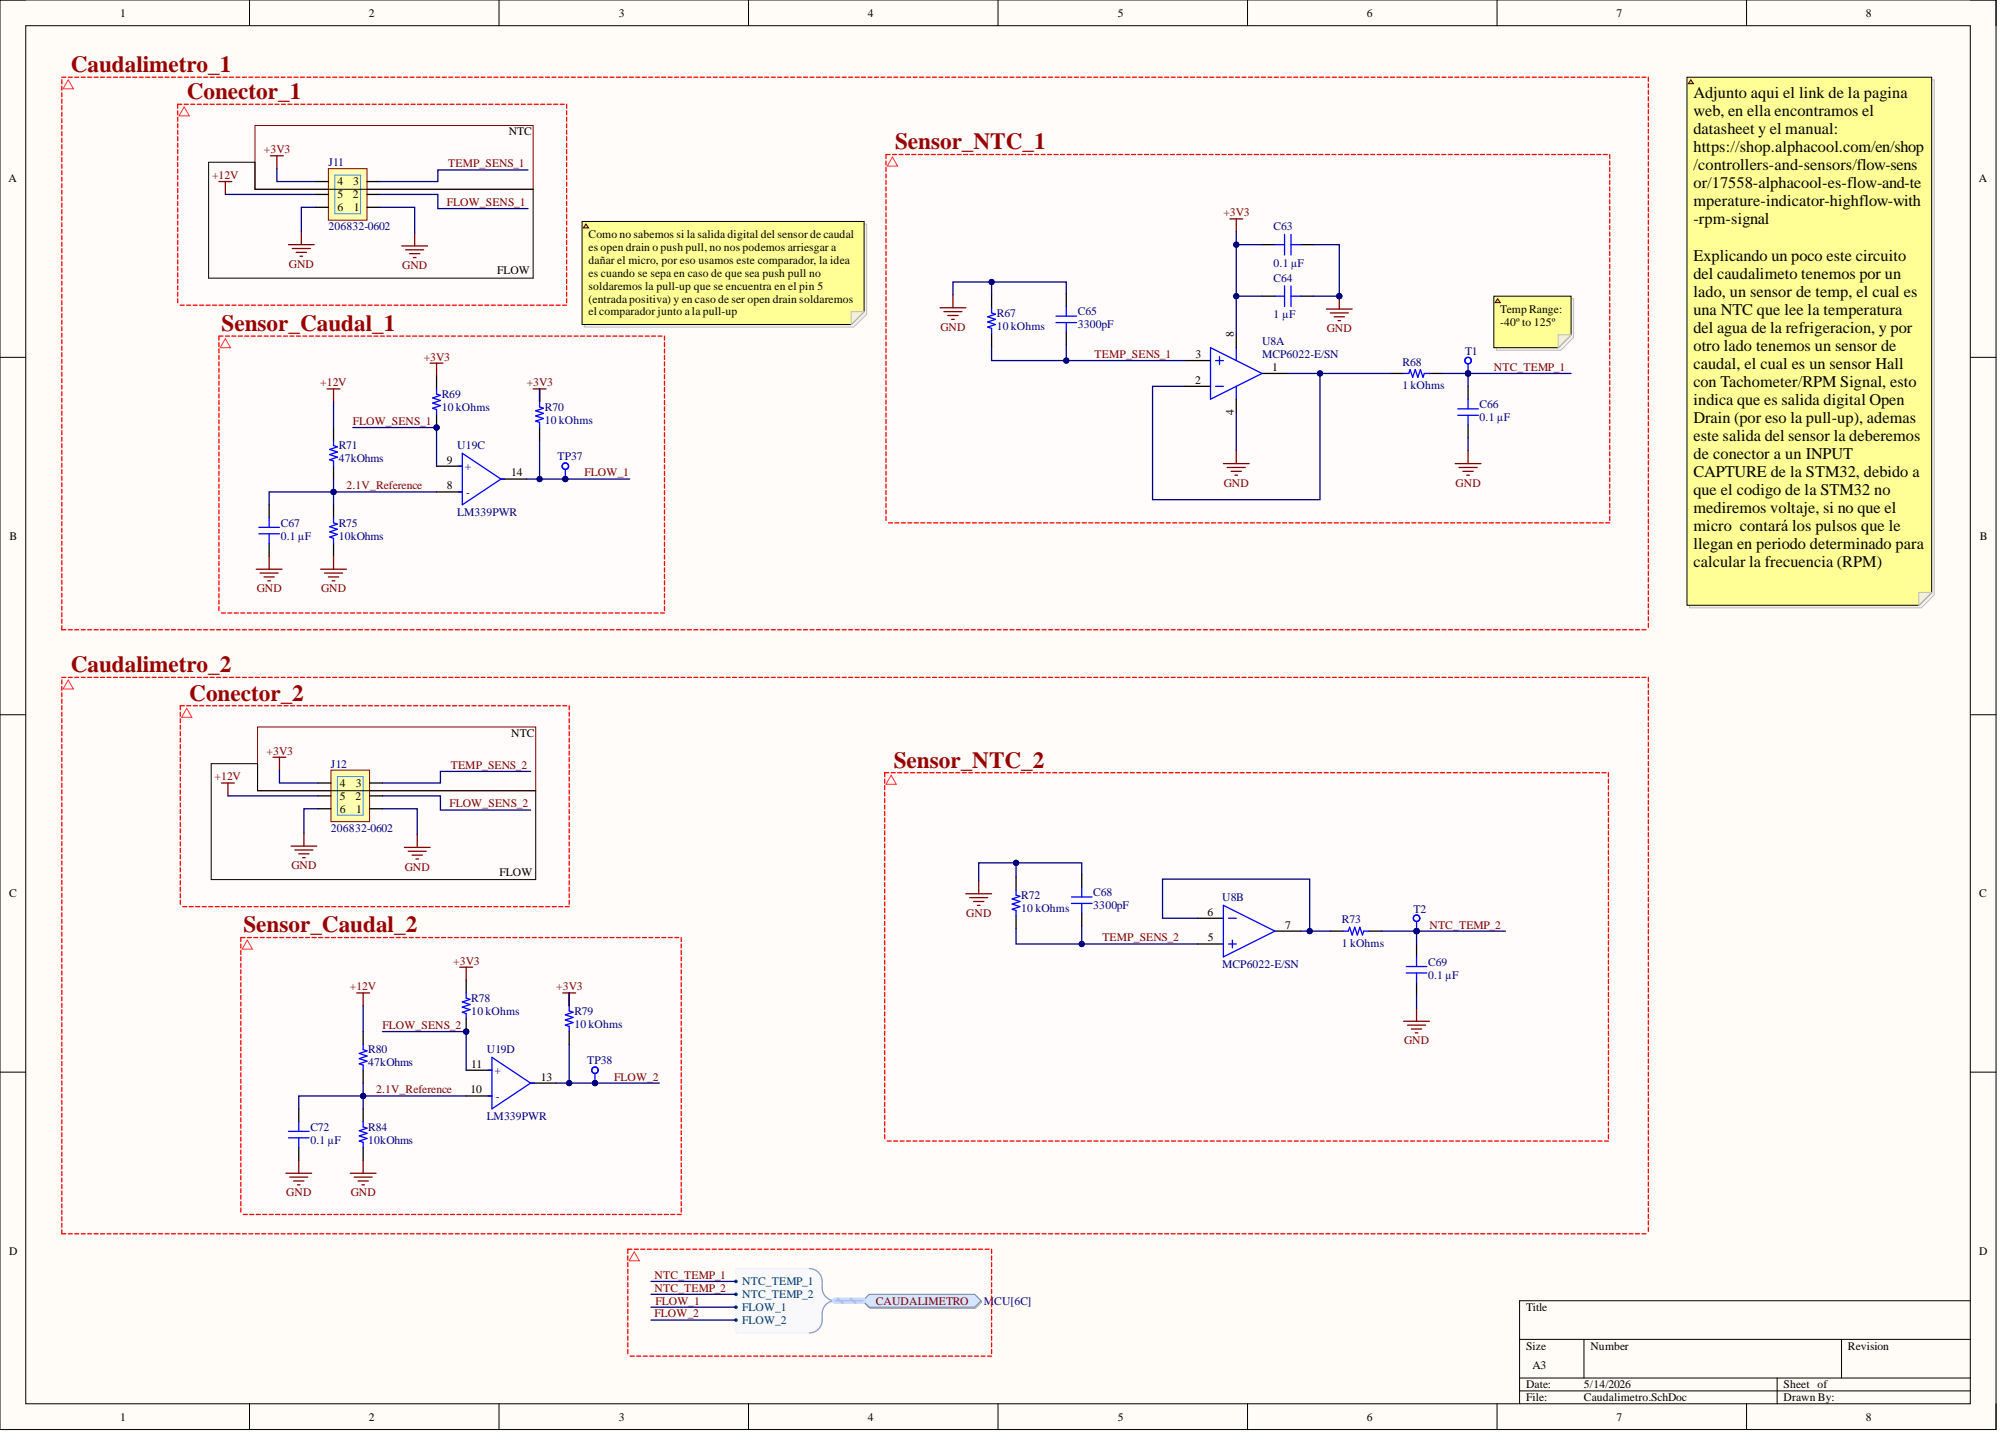
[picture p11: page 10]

Adjunto aqui el link de la pagina
web, en ella encontramos el
datasheet y el manual:
https://shop.alphacool.com/en/shop
/controllers-and-sensors/flow-sens
or/17558-alphacool-es-flow-and-te
mperature-indicator-highflow-with
-rpm-signal

FLOW_SENS_1

Como no sabemos si la salida digital del sensor de caudal
es open drain o push pull, no nos podemos arriesgar a
dañar el micro, por eso usamos este comparador, la idea
es cuando se sepa en caso de que sea push pull no
soldaremos la pull-up que se encuentra en el pin 5
(entrada positiva) y en caso de ser open drain soldaremos
el comparador junto a la pull-up

Explicando un poco este circuito
del caudalimeto tenemos por un
lado, un sensor de temp, el cual es
una NTC que lee la temperatura
del agua de la refrigeracion, y por
otro lado tenemos un sensor de
caudal, el cual es un sensor Hall
con Tachometer/RPM Signal, esto
indica que es salida digital Open
Drain (por eso la pull-up), ademas
este salida del sensor la deberemos
de conector a un INPUT
CAPTURE de la STM32, debido a

que el codigo de la STM32 no
mediremos voltaje, si no que el
micro contará los pulsos que le
llegan en periodo determinado para
calcular la frecuencia (RPM)

TEMP_SENS_2 | 5

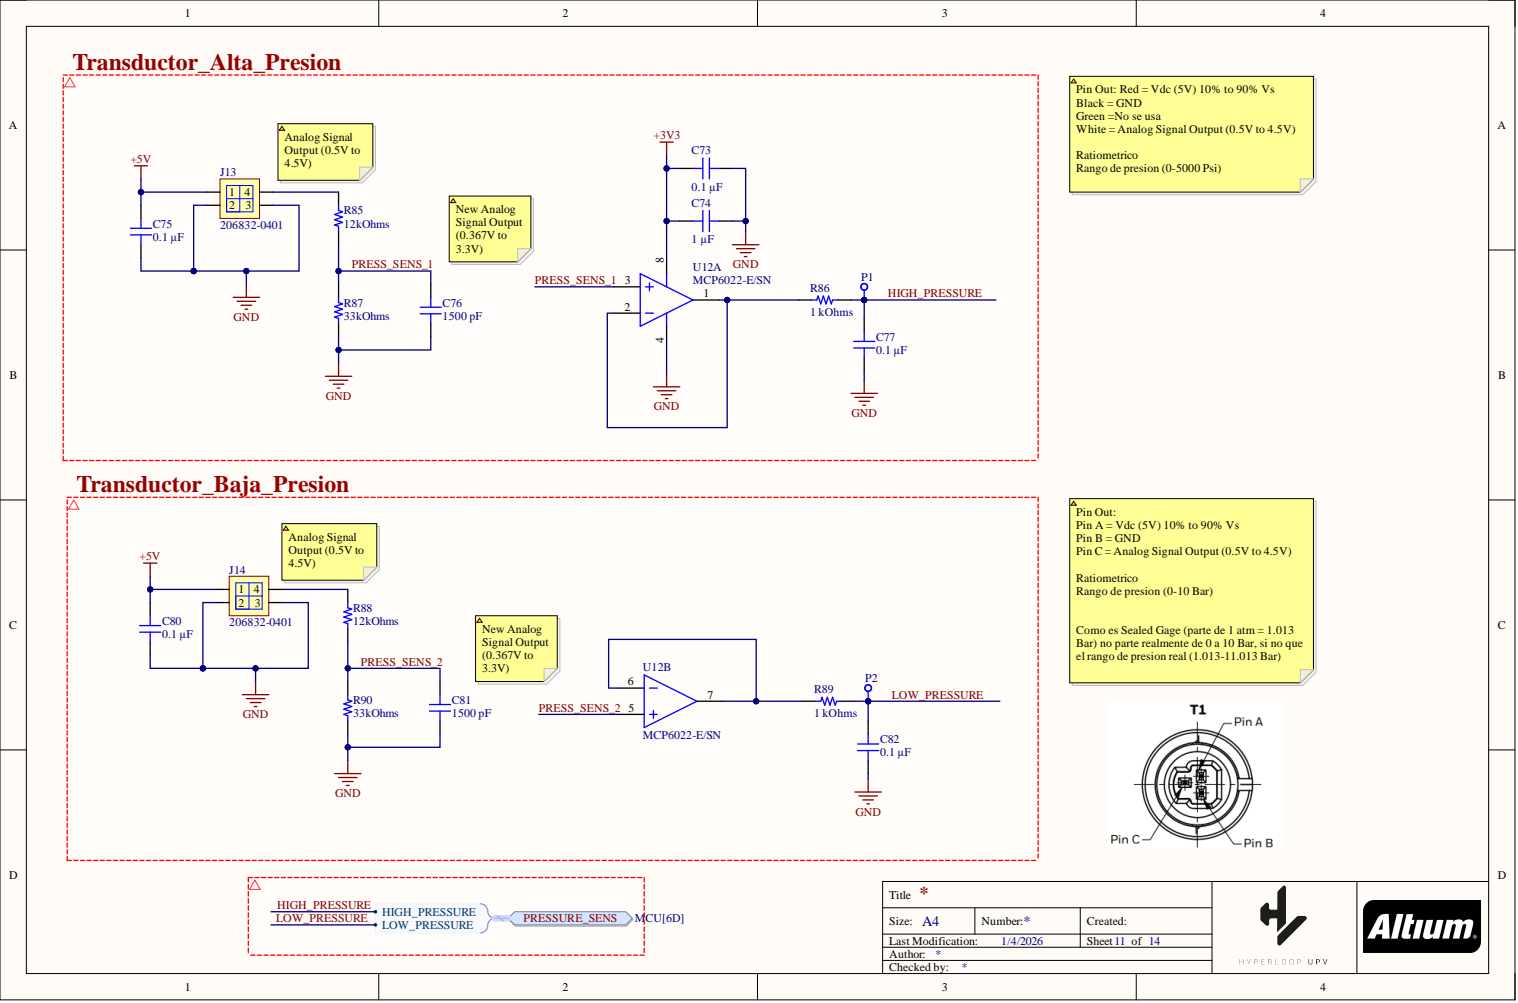
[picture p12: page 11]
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

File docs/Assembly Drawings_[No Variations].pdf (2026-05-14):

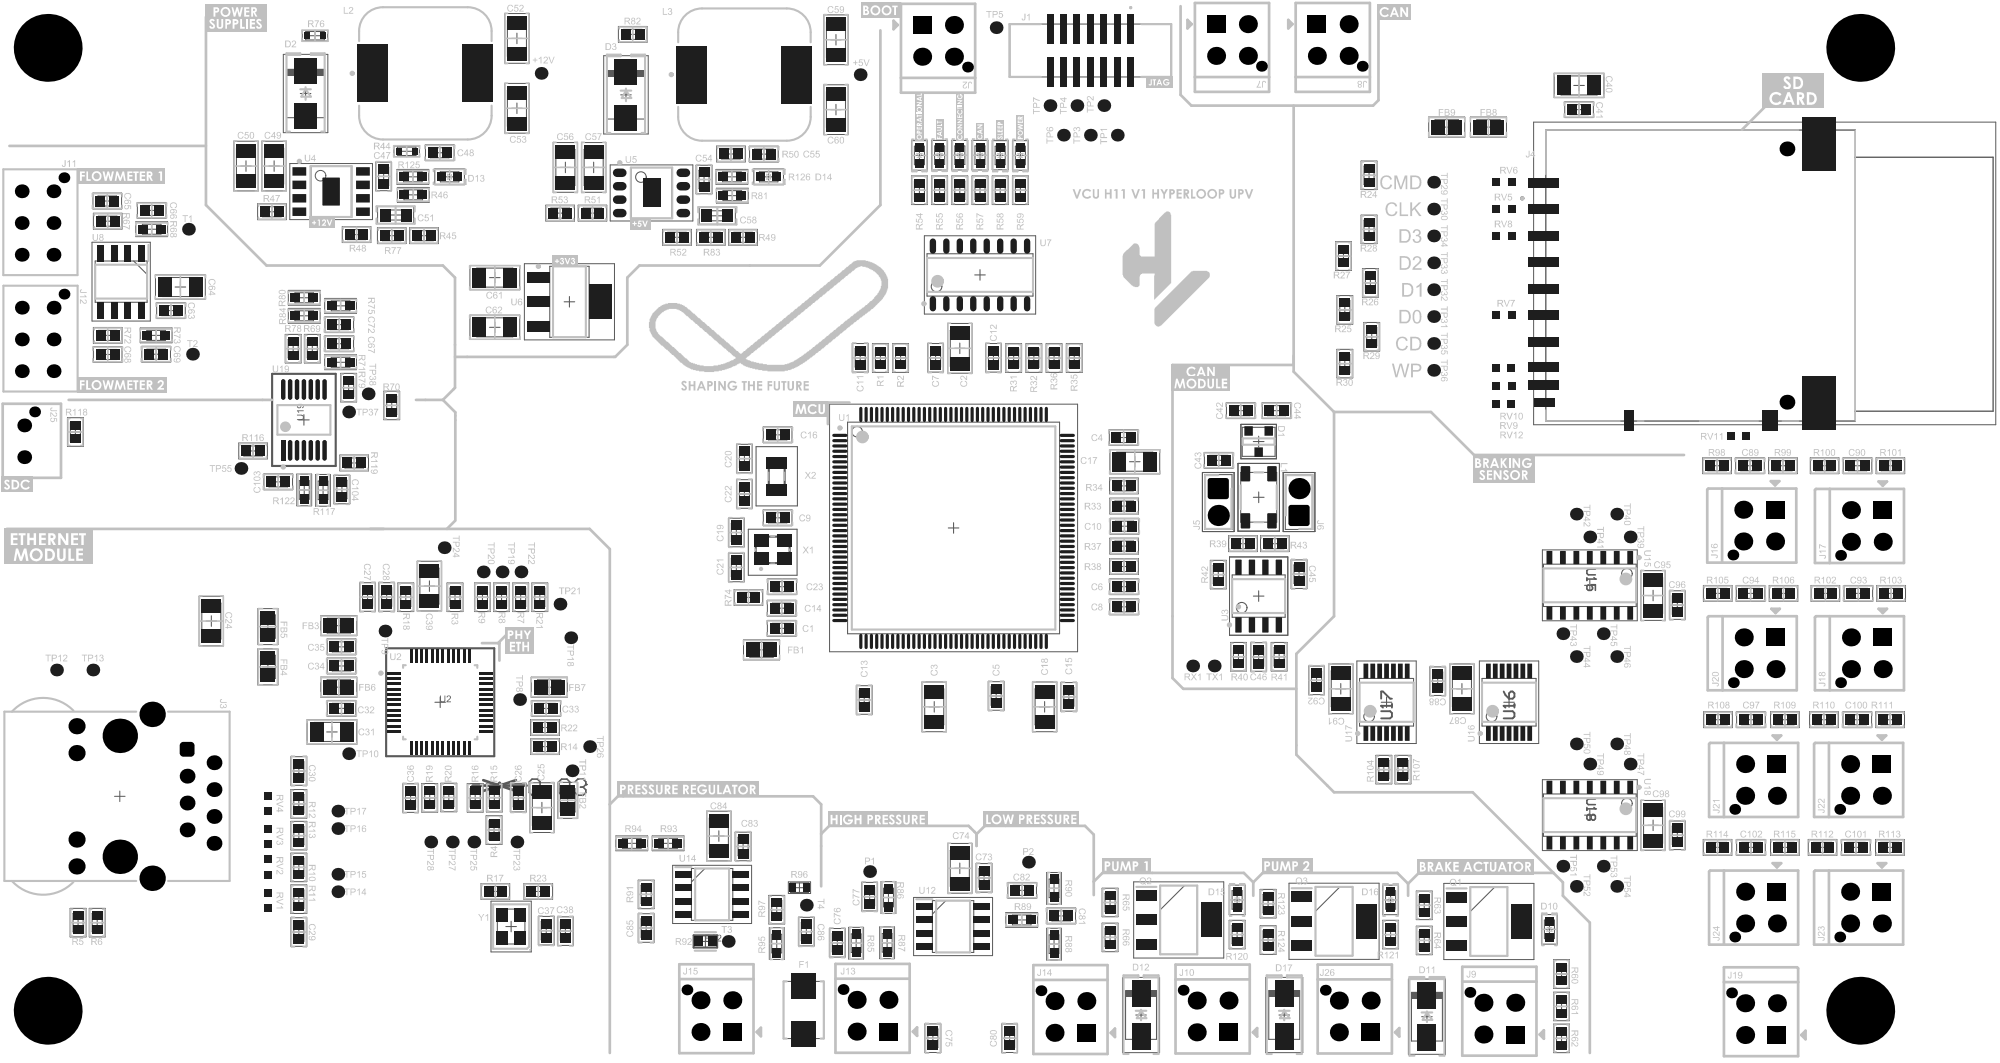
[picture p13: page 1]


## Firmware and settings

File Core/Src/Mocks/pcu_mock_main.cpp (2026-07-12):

#include "Mocks/MockPeer.hpp"
#include "ST-LIB.hpp"
#include "main.h"

namespace PCUMock {

inline constexpr const char* local_ip = "192.168.1.5";

inline constexpr auto eth = ST_LIB::EthernetDomain::Ethernet(
    MockPeer::ethernet_pinset,
    "00:80:e1:00:01:05",
    local_ip,
    "255.255.255.0"
);

using Board = MockPeer::Board<eth>;

enum class PCU_State : uint8_t {
    Connecting = 0,
    Idle = 1,
    Accelerating = 2,
    Fault = 3,
};

inline ST_LIB::EthernetDomain::Instance* ethernet = nullptr;
#ifndef MOCK_NO_LEDS
inline ST_LIB::DigitalOutputDomain::Instance* status_led = nullptr;
inline ST_LIB::DigitalOutputDomain::Instance* disconnected_led = nullptr;
#endif
inline ServerSocket* vcu_socket = nullptr;
inline bool connected_to_master = false;
inline bool was_connected_to_master = false;

inline PCU_State pcu_state = PCU_State::Idle;
inline float dummy_svpwm_params[4] = {};

inline HeapPacket* state_packet = nullptr;
inline DatagramSocket* state_udp = nullptr;

#ifndef MOCK_NO_LEDS
inline void update_leds() {
    MockPeer::update_connection_leds(
        connected_to_master,
        was_connected_to_master,
        *status_led,
        *disconnected_led
    );
}
#endif

inline void init() {
    ethernet = MockPeer::init_ethernet<Board, eth>();
#ifndef MOCK_NO_LEDS
    status_led = &Board::instance_of<MockPeer::status_led_req>();
    disconnected_led = &Board::instance_of<MockPeer::disconnected_led_req>();
    status_led->turn_off();
    disconnected_led->turn_off();
#endif
    vcu_socket = MockPeer::create_vcu_server_socket(local_ip);

    Diagnostics::install_ethernet_sink(vcu_socket);

    new HeapOrder(
        507,
        +[]() { pcu_state = PCU_State::Accelerating; },
        &dummy_svpwm_params[0],
        &dummy_svpwm_params[1],
        &dummy_svpwm_params[2],
        &dummy_svpwm_params[3]
    );
    new HeapOrder(
        508,
        +[]() { pcu_state = PCU_State::Idle; }
    );

    state_packet = new HeapPacket(static_cast<uint16_t>(553), &pcu_state);

    state_udp = new DatagramSocket("192.168.1.5", 50402, "192.168.1.3", 50402);

    Scheduler::register_task(
        16'670,
        +[]() { state_udp->send_packet(*state_packet); }
    );

#ifndef MOCK_NO_LEDS
    Scheduler::register_task(
        200'000,
        +[]() { update_leds(); }
    );
#endif
}

inline void update() {
    MockPeer::service_connection_status(
        *ethernet,
        vcu_socket,
        local_ip,
        connected_to_master,
        was_connected_to_master
    );
}

} // namespace PCUMock

int main(void) {
    Hard_fault_check();
    PCUMock::init();

    while (1) {
        PCUMock::update();
    }
}

extern "C" void Error_Handler(void) {
    PANIC("HAL error handler triggered");
    while (1) {
    }
}

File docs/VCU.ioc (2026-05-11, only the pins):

Mcu.UserName=STM32H723ZGTx
PA1.Signal=ETH_REF_CLK
PA11.Signal=FDCAN1_RX
PA12.Signal=FDCAN1_TX
PA13(JTMS/SWDIO).Signal=DEBUG_JTMS-SWDIO
PA14(JTCK/SWCLK).Signal=DEBUG_JTCK-SWCLK
PA15(JTDI).Signal=DEBUG_JTDI
PA2.Signal=ETH_MDIO
PA5.Signal=ADCx_INP19
PA6.Signal=S_TIM13_CH1
PA7.Signal=ETH_CRS_DV
PA8.Signal=GPIO_Output
PB11.Signal=ETH_TX_EN
PB12.Signal=ETH_TXD0
PB13.Signal=ETH_TXD1
PB3(JTDO/TRACESWO).Signal=DEBUG_JTDO-SWO
PC1.Signal=ETH_MDC
PC10.Signal=SDMMC1_D2
PC11.Signal=SDMMC1_D3
PC12.Signal=SDMMC1_CK
PC14-OSC32_IN.Signal=RCC_OSC32_IN
PC15-OSC32_OUT.Signal=RCC_OSC32_OUT
PC4.Signal=ETH_RXD0
PC5.Signal=ETH_RXD1
PC8.Signal=SDMMC1_D0
PC9.Signal=SDMMC1_D1
PD14.Signal=GPIO_Input
PD15.Signal=GPIO_Output
PD2.Signal=SDMMC1_CMD
PD5.Signal=USART2_TX
PD6.Signal=USART2_RX
PE13.Signal=GPIO_Output
PE14.Signal=GPIO_Output
PE15.Signal=GPIO_Output
PF0.Signal=TIM23_CH1
PF1.Signal=S_TIM23_CH2
PF11.Signal=ADC1_INP2
PF12.Signal=ADC1_INP6
PF13.Signal=GPIO_Input
PF14.Signal=GPIO_Output
PF3.Signal=ADC3_INP5
PF4.Signal=ADC3_INP9
PF6.Signal=GPXTI6
PG10.Signal=GPIO_Output
PG11.Signal=GPIO_Output
PG12.Signal=GPIO_Output
PG13.Signal=GPIO_Output
PG3.Signal=GPIO_Input
PG4.Signal=GPIO_Input
PG9.Signal=GPIO_Output
PH0-OSC_IN.Signal=RCC_OSC_IN
PH1-OSC_OUT.Signal=RCC_OSC_OUT

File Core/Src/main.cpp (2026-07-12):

#include "ST-LIB.hpp"
#include "VCU.hpp"
#include "main.h"

using namespace ST_LIB;

int main(void) {
    for (volatile uint32_t i = 0; i < 25000000;) {
        auto j = i;
        i = j + 1;
        __NOP();
    }
    VCU::init();

    while (1) {
        VCU::update();
    }
}

extern "C" void Error_Handler(void) {
    PANIC("HAL error handler triggered");
    while (1) {
    }
}

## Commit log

2026-05-11 Initial structure
    [STEP_[No Variations] for PCB.PcbDoc.step]
2026-05-14 Updated with latest Altium version
    [BOM_[No Variations].csv, STEP_[No Variations] for PCB.PcbDoc.step]
2026-05-23 Implemented state machine and brakes
2026-05-24 Pressure sensors characterized
2026-06-03 Redefined state machine entirely
    [vcu_state_machine.yaml]
2026-06-03 Added tapes protection and pressure warning
    [vcu_state_machine.yaml]
2026-07-08 Added braking from active modes
    [vcu_state_machine.yaml]
2026-07-09 fix: Remove unused packets from mocks
    [pcu_mock_main.cpp]
2026-07-11 Add initial brakes check
2026-07-11 feat: Update hard fault leds
2026-07-11 feat: Add HAL_Delay for the switch reset
2026-07-14 Brakes status renamed and using enum instead of bool
    [vcu_state_machine.yaml]
2026-07-15 inverted brakes logic
2026-07-15 finally brakes logic correct
2026-07-15 adj hash switch
2026-07-16 Added per-board connection enablement
2026-07-16 brakes action fixed
2026-07-16 brakes logic inverted
2026-07-16 removed redundant measurement
    [vcu_state_machine.yaml]
